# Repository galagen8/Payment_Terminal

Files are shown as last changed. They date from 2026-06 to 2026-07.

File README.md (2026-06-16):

# Payment-Donation-Terminal

A hardware and software solution designed as an automated donation terminal for a church. The system accepts cash (banknotes) and triggers electrical decorative candles to light up for a specific duration based on the donation amount.
<br><br>

<p align="center">
Finished Donation Terminal in Installation
</p>

<br>
This repository contains the complete design files, including MCU firmware, PCB layouts, and 3D mechanical models.

---

## Tech Stack & Tools

* MCU & Firmware: STM32G030K8T6 (Production), NUCLEO-F446RE (Prototyping) using STM32CubeHAL
* ECAD: Altium Designer
* MCAD: SolidWorks
* Peripherals: ICT NK77 Bill Acceptor

---

## Features

* Banknote Validation: Integrated with an ICT NK77 Bill Acceptor using a reliable pulse-based protocol.
* Cost-Optimized Hardware: Built on a budget-friendly and reliable STM32G0 MCU, utilizing STM32CubeHAL for seamless firmware portability from the initial STM32F4 prototype.
* Hardware-Driven Power Gating: Candles are hardwired and controlled via low-side NPN transistor switches, eliminating wireless reliability issues and fast battery discharge.
* Scalable Output: The custom PCB features parallel sockets for each channel, supporting up to 6 candles in total (powered by a dedicated stable 5V PSU).

---

### PCB Design & Assembly

*Actual assembled board:*

<p align="center">
Custom PCB Assembly
<p/>
<br>

*Topology / 3D visualization in Altium Designer:*

<p align="center">
Altium Designer PCB Layout
<p/>
<br>

---

### Enclosure Design & System Sub-Assembly

*3D model of the Enclosure in SolidWorks:*

<p align="center">
SolidWorks Enclosure Design
<p/>
<br>

*System Sub-Assembly and Power Distribution:*

<p align="center">
System Sub-Assembly and Power Management
<p/>
<br>

---

## How It Works & Algorithm

### 1. Power-On Self-Test (POST) / Diagnostics
Upon boot, the system runs a quick diagnostic routine: all candles light up sequentially for 1 second each to verify wiring, transistor switching, and LED functionality before entering normal operation mode.

### 2. Pulse Interfacing
The ICT NK77 Bill Acceptor is configured via DIP switches to use the pulse protocol, transmitting 1 pulse per 10 THB (e.g., a 100 THB banknote generates 10 pulses). The STM32 MCU captures and processes these incoming pulses.

### 3. Candle Control Logic
The lighting sequence dynamically scales with the donation amount, managed by a rolling timer:
* 1st Level Donation: The 1st candle lights up for 10 minutes.
* 2nd Level Donation: If another bill is inserted while the 1st candle is active, the 2nd candle turns on, and the 10-minute countdown resets for both.
* 3rd Level Donation: Subsequent insertions activate the 3rd candle and renew the master 10-minute timer.

---

## Repository Structure

* /Firmware — STM32CubeIDE project and source code (HAL-based).
* /Altium — Schematic and PCB layout files (manufactured via JLCPCB, hand-assembled).
* /SolidWorks — 3D models and manufacturing drawings for the HLP enclosure.

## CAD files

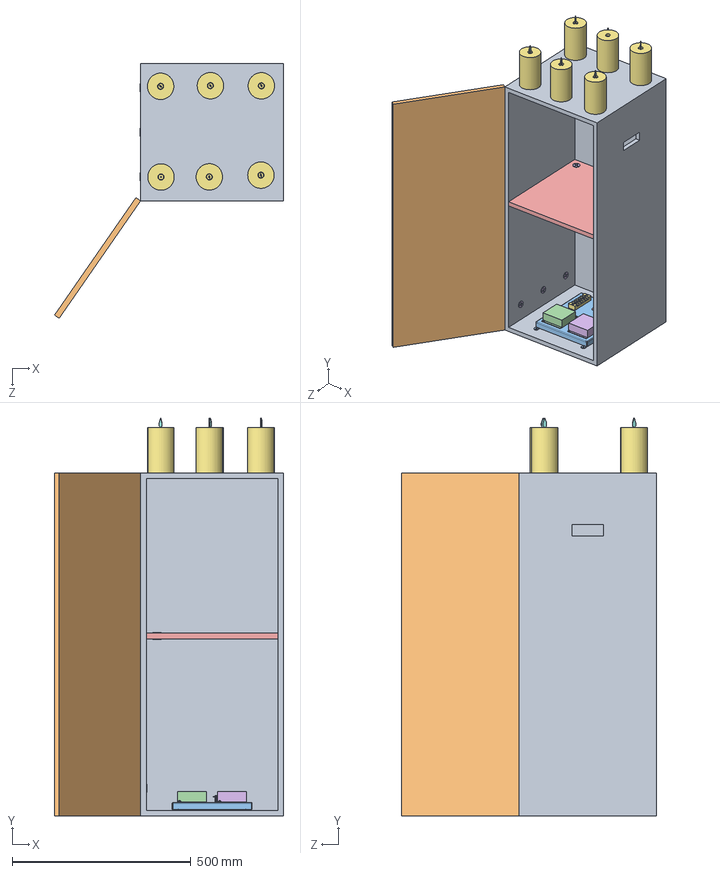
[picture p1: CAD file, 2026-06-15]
Solidworks/ASSY_WHOLE_DON-BOX_1.SLDASM
641.0 x 1114.0 x 712.7 mm
WOOD_BOX_2
WOOD_DOOR_2
SHEET_1
POWER_SUPPLY_MEANWELL_LRS-35_5V-7A_1
PCB_MOCKUP_1
POWER_SUPPLY_MEANWELL_LRS-35-12_12V-3A_1
TB-6_TERMINAL-1
BOLT_PH-M3-6MM x 4
STAND_M3_PLASTIC_1 x 4
WASHER_M3_8mm_1 x 18
BOLT_PH-M3-10MM x 6
NUT_M3_METAL_1 x 10
WOOD_SHELF_1
SLEEVE_SILICON_20MM-1 x 8
CANDLE_BODY_1 x 6
CANDLE_FLAME_1 x 6

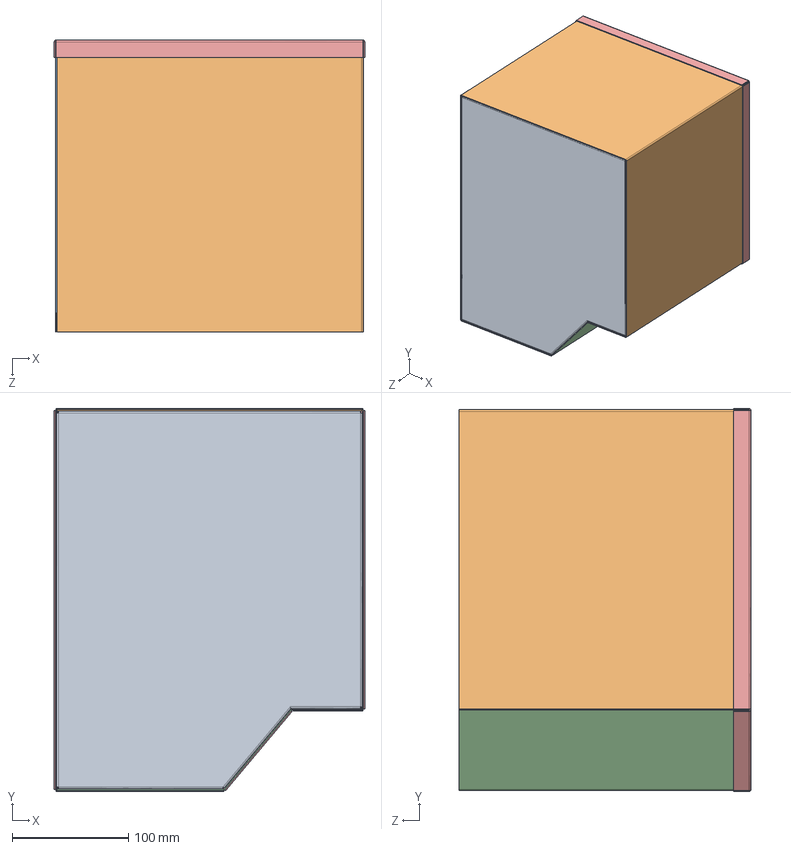
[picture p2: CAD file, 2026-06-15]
Solidworks/ASSEM_MONEY_BOX-1.SLDASM
267.0 x 329.1 x 251.0 mm
MONEY-BOX_PART_2-1
MONEY-BOX_PART_1-2
MONEY-BOX_PART_3-1
MONEY-BOX_PART_4-1
MONEY-BOX_PART_5-1

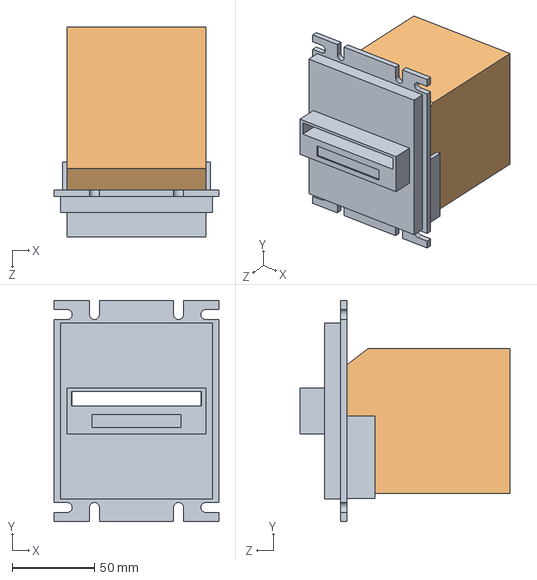
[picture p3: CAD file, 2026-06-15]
Solidworks/NK77_ASSEM_1.SLDASM
100.0 x 134.0 x 127.5 mm
NK77_COVER
NK77_ACCEPTOR

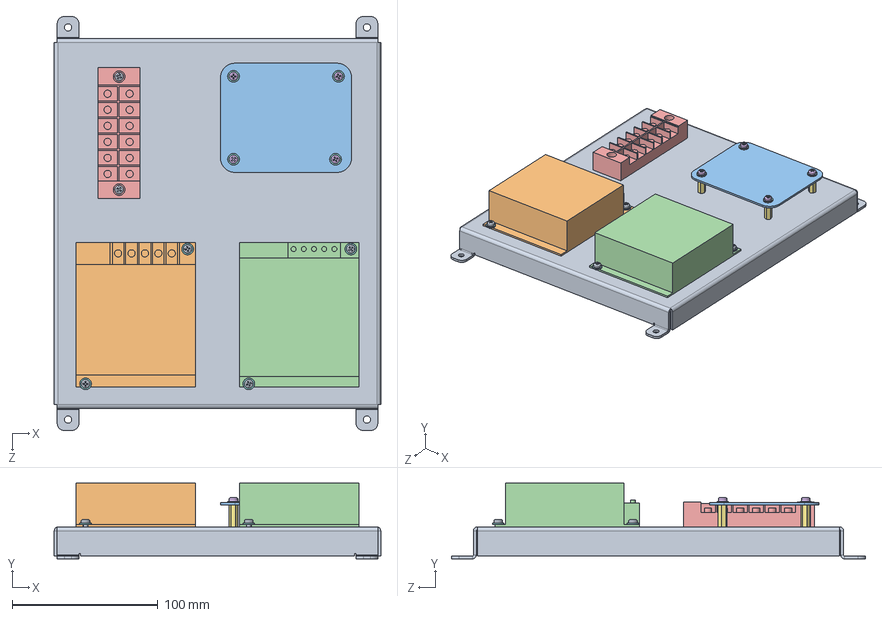
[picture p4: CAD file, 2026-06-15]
Solidworks/ASSY_SHIELD_ELEC_1.SLDASM
224.0 x 52.0 x 284.0 mm
SHEET_1
POWER_SUPPLY_MEANWELL_LRS-35_5V-7A_1
PCB_MOCKUP_1
POWER_SUPPLY_MEANWELL_LRS-35-12_12V-3A_1
TB-6_TERMINAL-1
BOLT_PH-M3-6MM x 4
STAND_M3_PLASTIC_1 x 4
WASHER_M3_8mm_1 x 18
BOLT_PH-M3-10MM x 6
NUT_M3_METAL_1 x 10

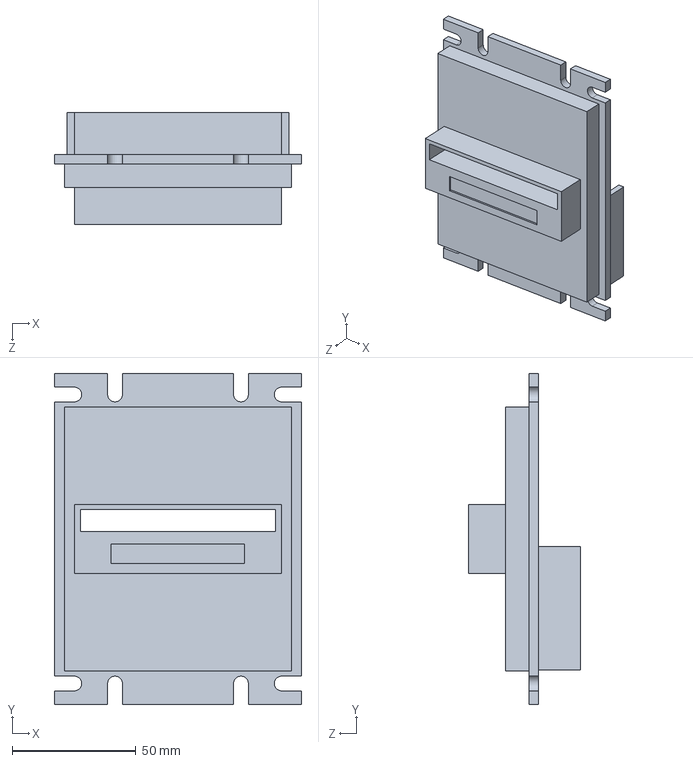
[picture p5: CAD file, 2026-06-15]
Solidworks/NK77_COVER.SLDPRT
100.0 x 134.0 x 45.5 mm

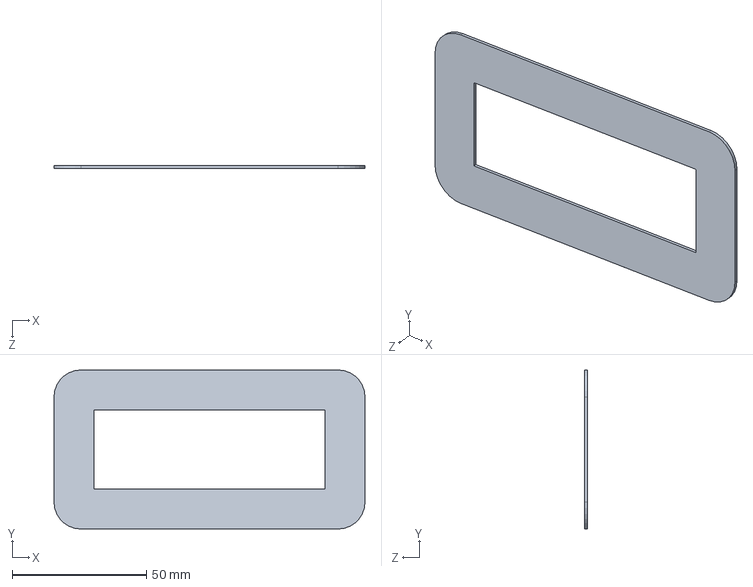
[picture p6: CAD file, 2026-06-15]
Solidworks/VISOR_NK77-1.SLDPRT
116.0 x 59.3 x 1.00 mm

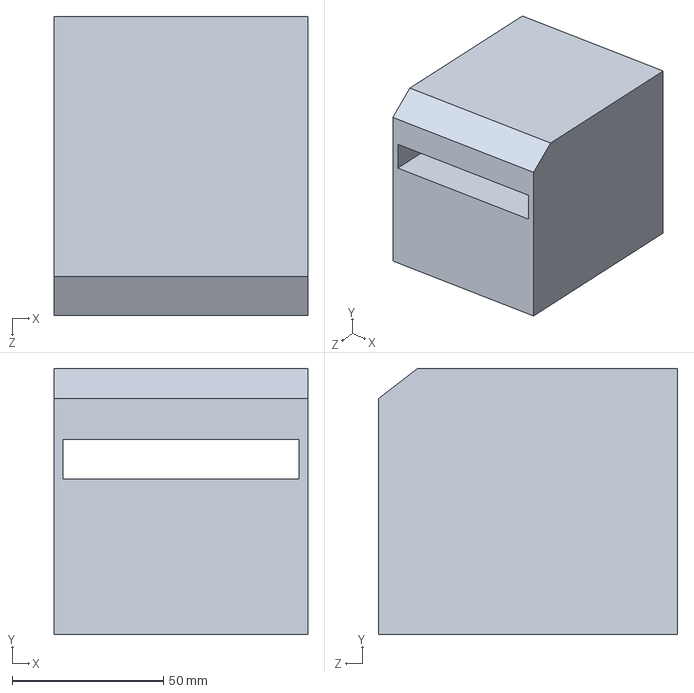
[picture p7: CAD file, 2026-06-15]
Solidworks/NK77_ACCEPTOR.SLDPRT
84.0 x 88.0 x 99.0 mm

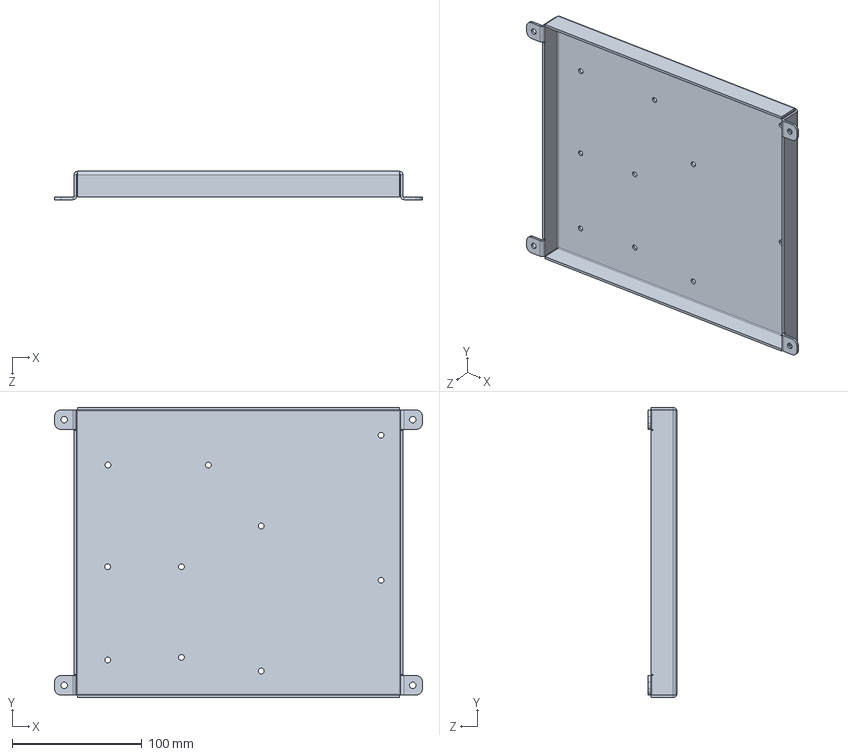
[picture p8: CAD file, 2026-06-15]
Solidworks/SHEET_1.SLDPRT
284.0 x 224.0 x 22.0 mm

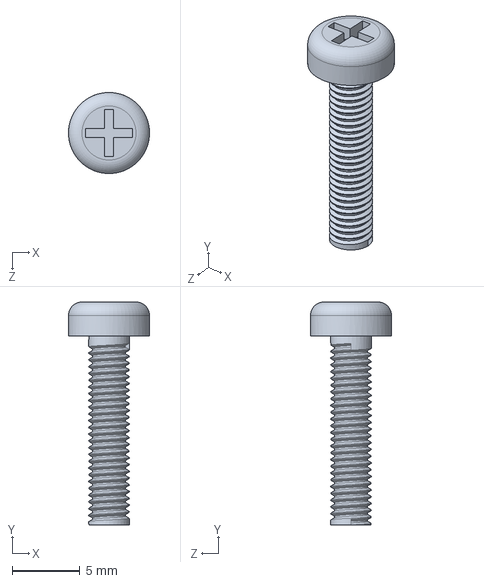
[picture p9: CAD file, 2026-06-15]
Solidworks/BOLT_PH-M3-10MM_1.SLDPRT
6.00 x 16.5 x 6.00 mm

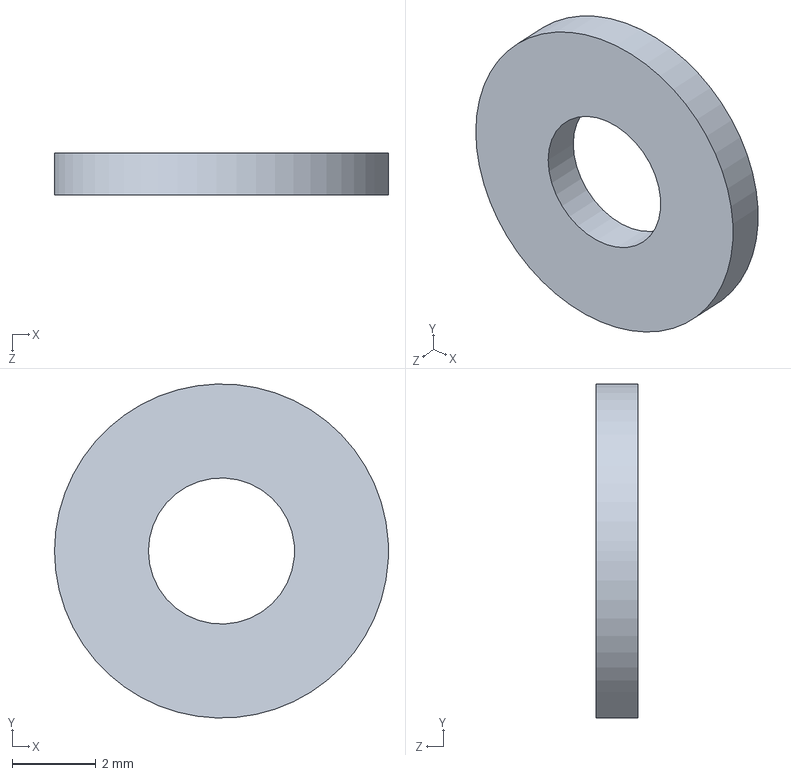
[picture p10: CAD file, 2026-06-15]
Solidworks/WASHER_M3_8mm_1.SLDPRT
8.00 x 8.00 x 1.00 mm

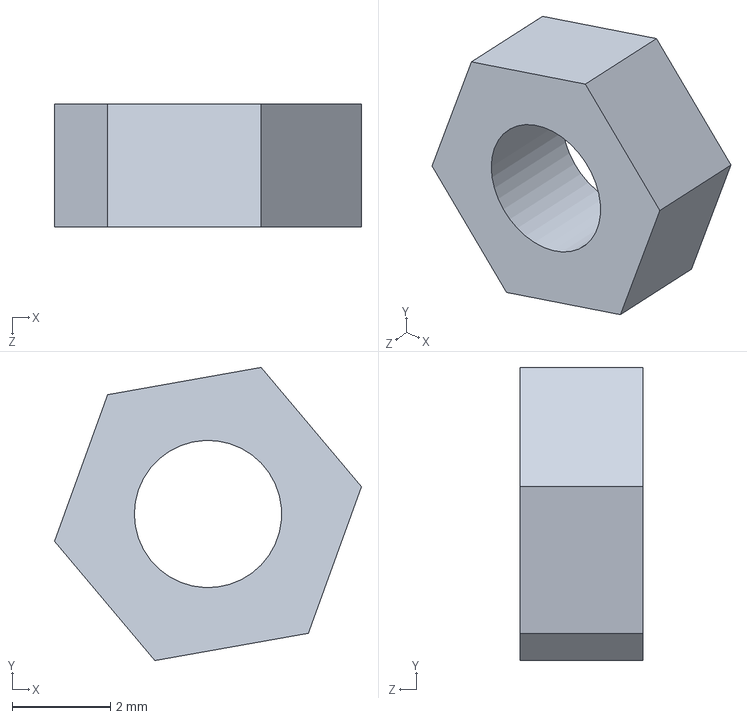
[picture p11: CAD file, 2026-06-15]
Solidworks/NUT_M3_METAL_1.SLDPRT
6.25 x 5.97 x 2.50 mm

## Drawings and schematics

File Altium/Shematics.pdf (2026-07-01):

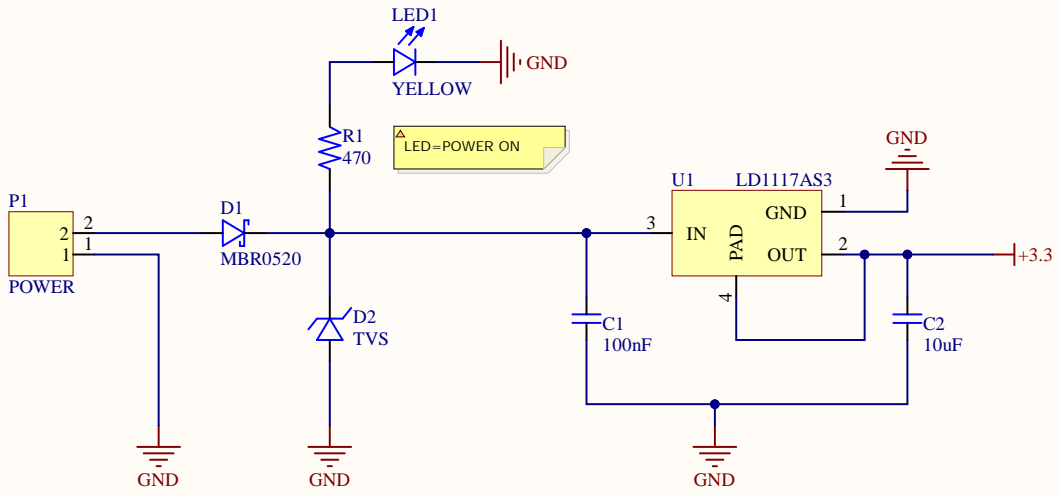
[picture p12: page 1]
Title; Size; Revisio; Date:; Sheet o; File:; K:\DG\..\Power.SchDo; Drawn B; GND; OUT; PAD 4; D2 TVS; LED1; YELLOW; POWER

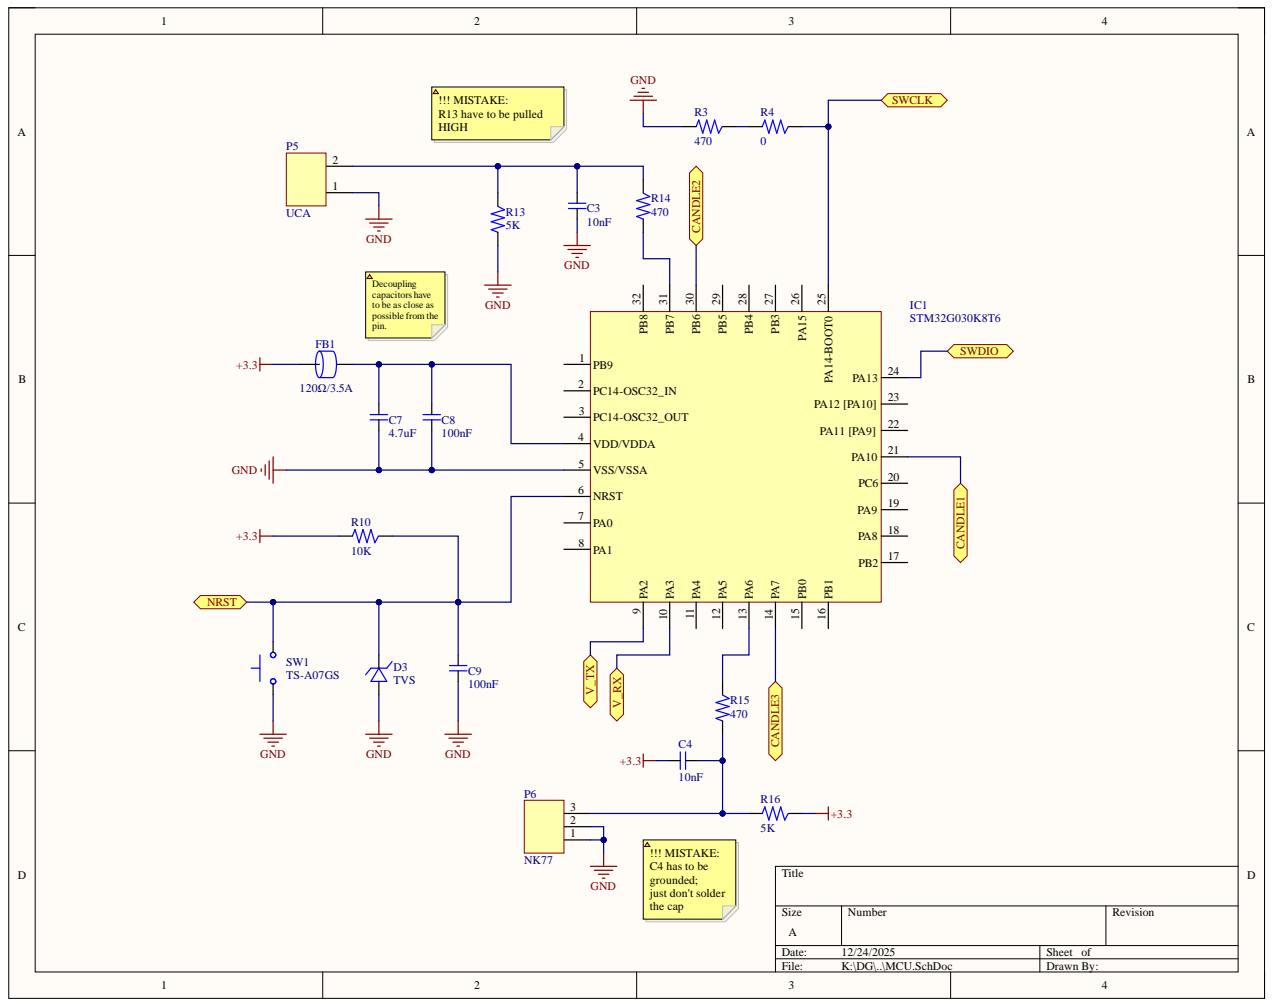
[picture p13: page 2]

!!! MISTAKE:
R13 have to be pulled
HIGH

Decoupling
capacitors have
to be as close as
possible from the
pin.

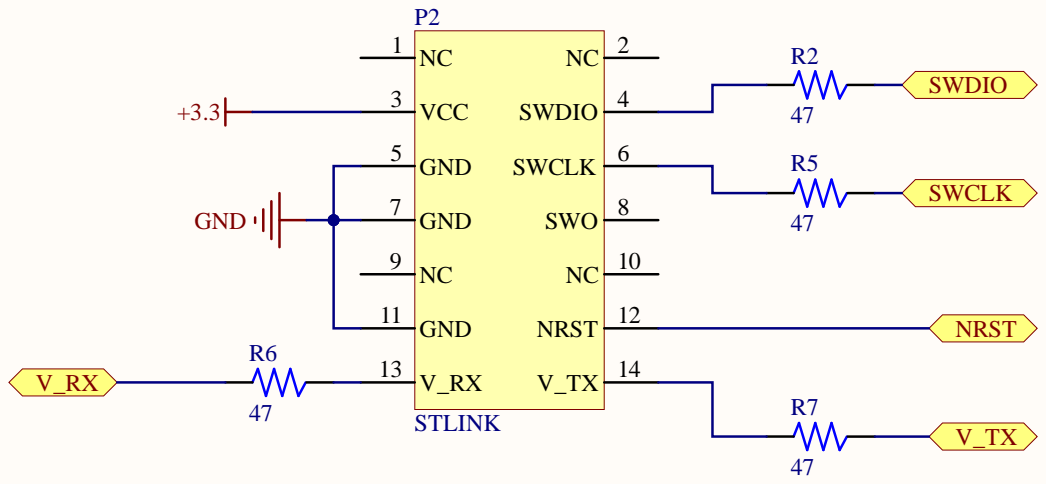
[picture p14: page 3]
Title; Size; Number; Revision; File:; K:\DG\..\STlink-plug.SchDoc; Drawn By:; VCC 3; SWDIO 4; GND 5; SWCLK 6; GND 7; SWO 8; GND 11; NRST 12; STLINK; NRST; SWDIO; SWCLK; GND

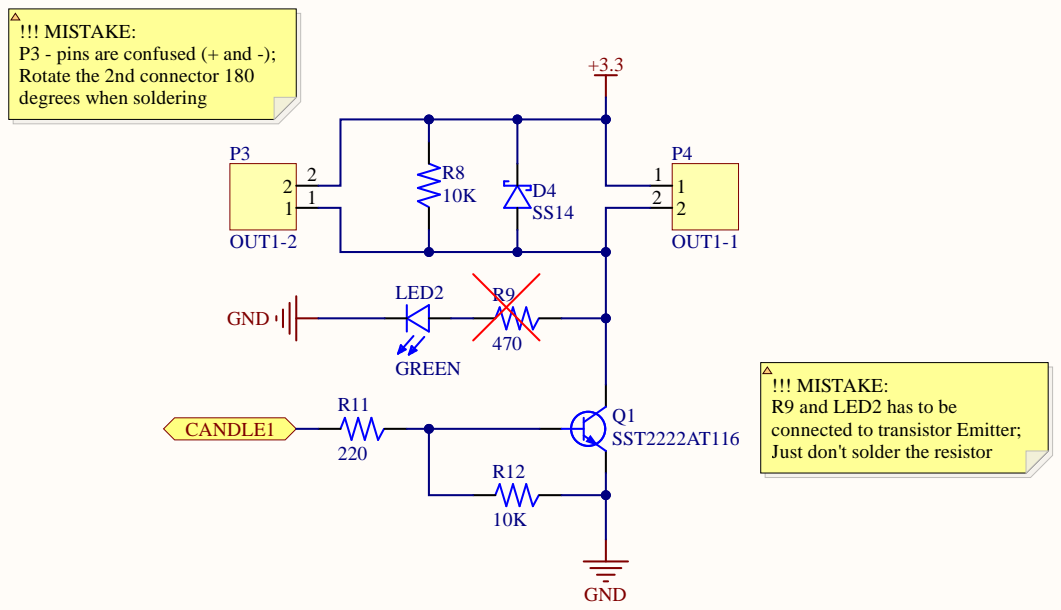
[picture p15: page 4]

!!! MISTAKE:
P3 - pins are confused (+ and -);
Rotate the 2nd connector 180
degrees when soldering

R9 and LED2 has to be
connected to transistor Emitter;
Just don't solder the resistor

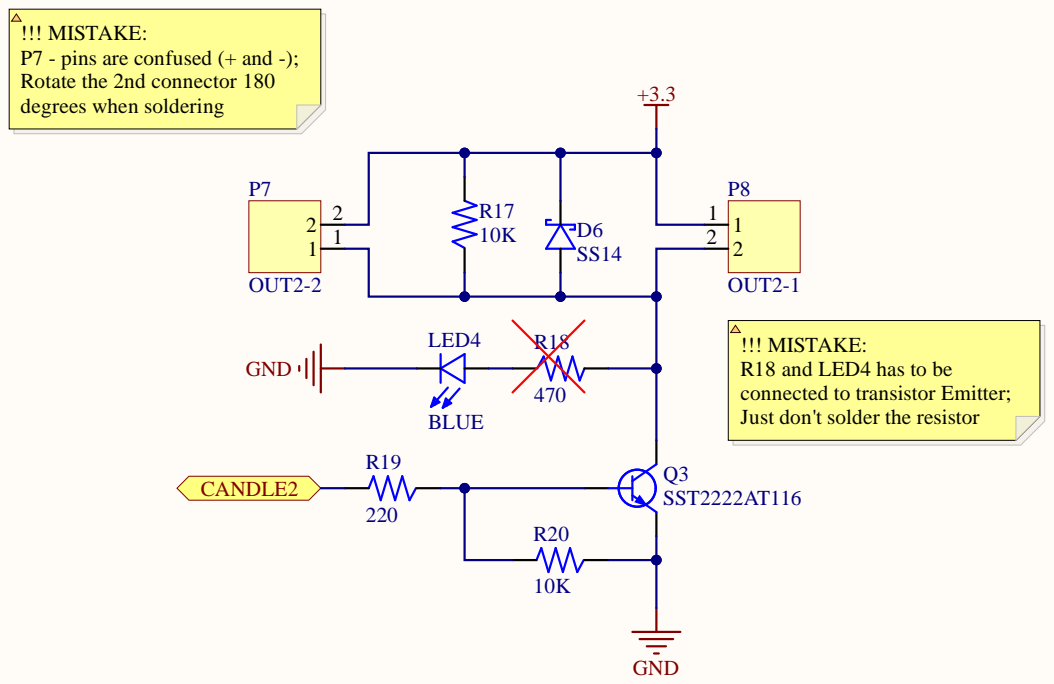
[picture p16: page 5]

!!! MISTAKE:
P7 - pins are confused (+ and -);
Rotate the 2nd connector 180
degrees when soldering

R18 and LED4 has to be
connected to transistor Emitter;
Just don't solder the resistor

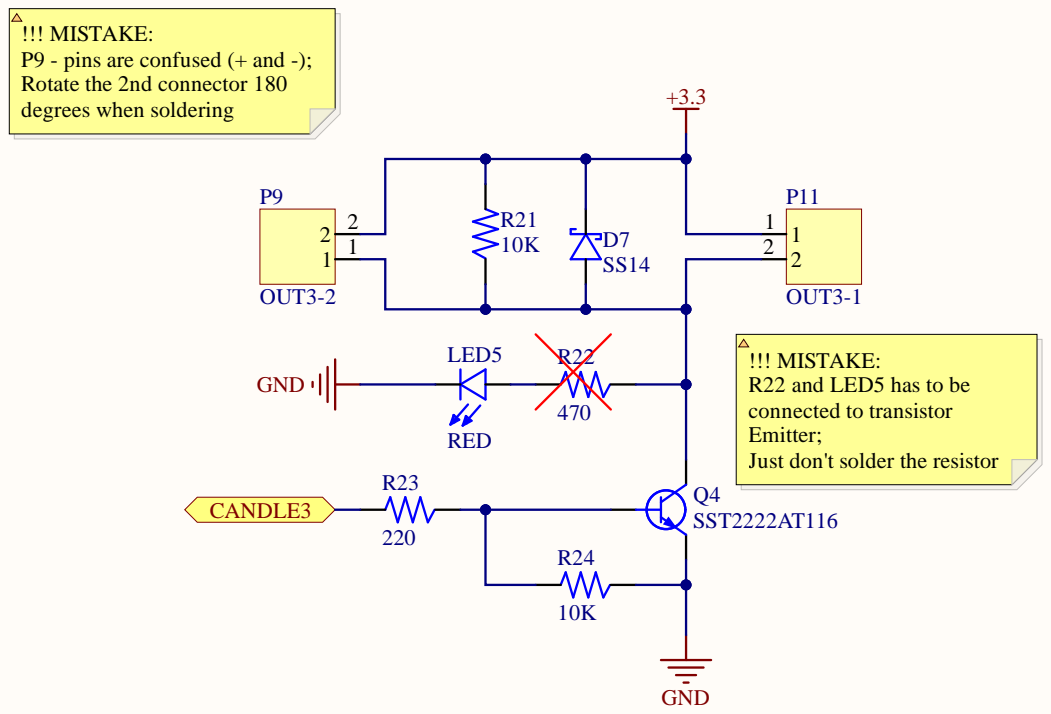
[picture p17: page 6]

!!! MISTAKE:
P9 - pins are confused (+ and -);
Rotate the 2nd connector 180
degrees when soldering

R22 and LED5 has to be
connected to transistor
Emitter;
Just don't solder the resistor
SST2222AT116

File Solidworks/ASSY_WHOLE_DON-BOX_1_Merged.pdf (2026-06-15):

# CUT

E | E

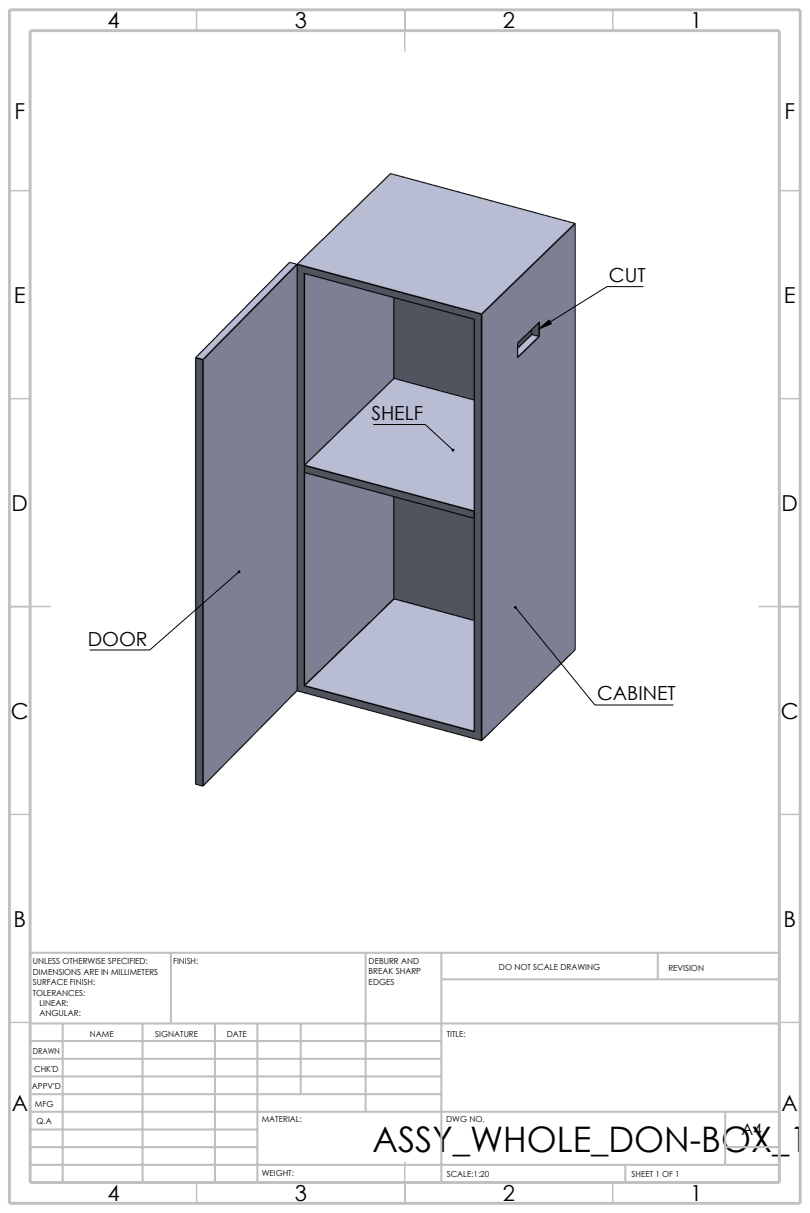
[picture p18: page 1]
DOOR; CABINET; SHELF; FINISH:; DEBURR AND; BREAK SHARP EDGES; DO NOT SCALE DRAWING; REVISION; SCALE:1:20; SHEET 1 OF 1; WEIGHT:; ASSY_WHOLE_DON-BOX_1

UNLESS OTHERWISE SPECIFIED:
DIMENSIONS ARE IN MILLIMETERS
SURFACE FINISH:
TOLERANCES:
LINEAR:
ANGULAR:

NAME | SIGNATURE | DATE | | | | TITLE:

DRAWN
CHK'D
APPV'D
MFG
Q.A | | | | MATERIAL: | DWG NO. | A4

16.00
E | E

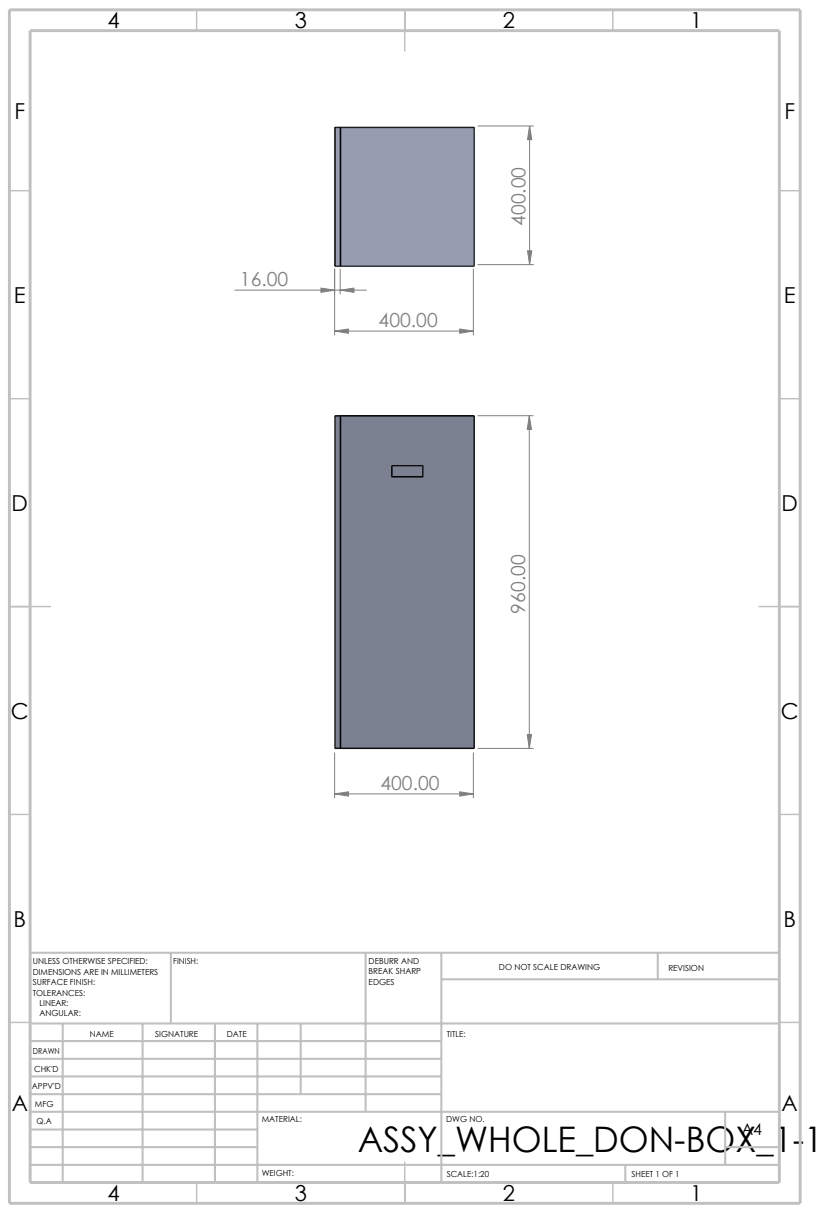
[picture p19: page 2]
FINISH:; DEBURR AND; BREAK SHARP EDGES; DO NOT SCALE DRAWING; REVISION; ASSY_WHOLE_DON-BOX_1-1

UNLESS OTHERWISE SPECIFIED:
DIMENSIONS ARE IN MILLIMETERS
SURFACE FINISH:
TOLERANCES:
LINEAR:
ANGULAR:

NAME | SIGNATURE | DATE | TITLE:

DRAWN
CHK'D
APPV'D
MFG

89.00

E | E

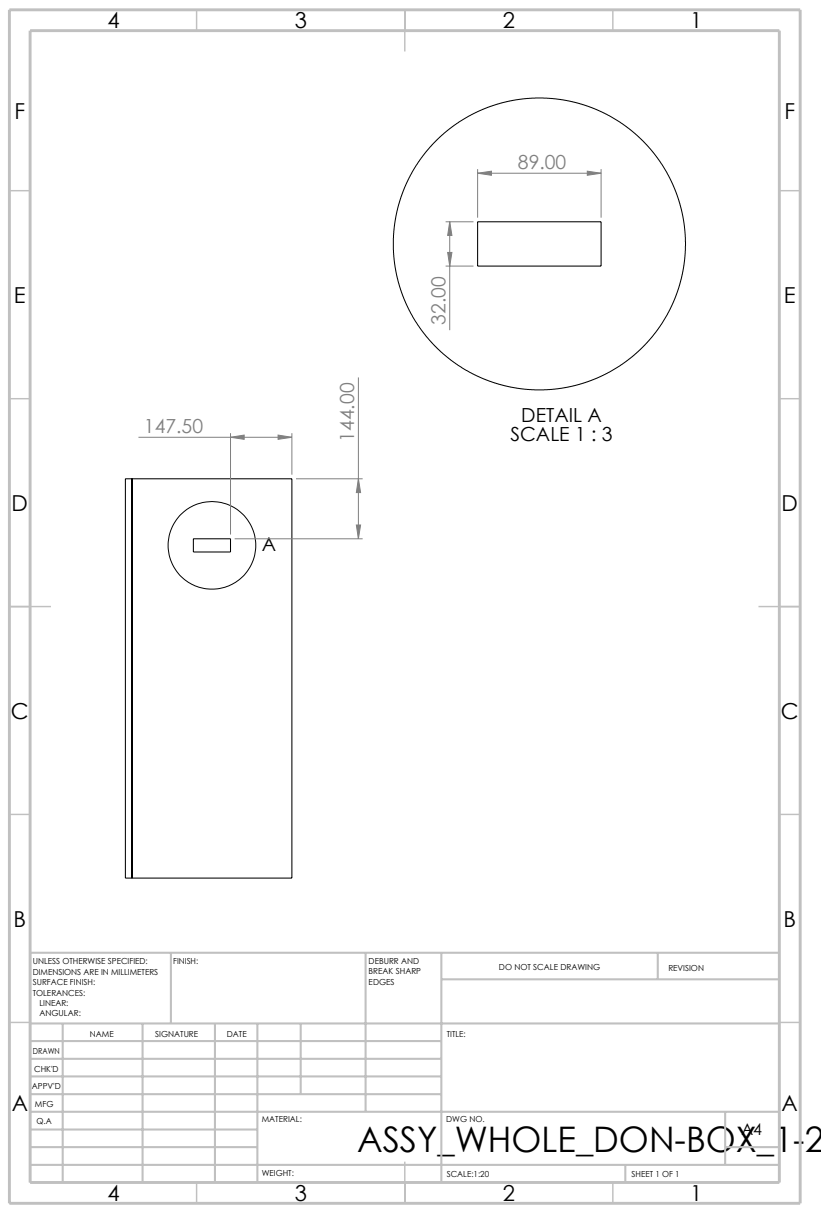
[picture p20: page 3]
DETAIL A SCALE 1 : 3; FINISH:; DEBURR AND; BREAK SHARP EDGES; DO NOT SCALE DRAWING; REVISION

UNLESS OTHERWISE SPECIFIED:
DIMENSIONS ARE IN MILLIMETERS
SURFACE FINISH:
TOLERANCES:
LINEAR:
ANGULAR:

NAME | SIGNATURE | DATE | TITLE:

DRAWN
CHK'D
APPV'D
MFG

E | E
F | F

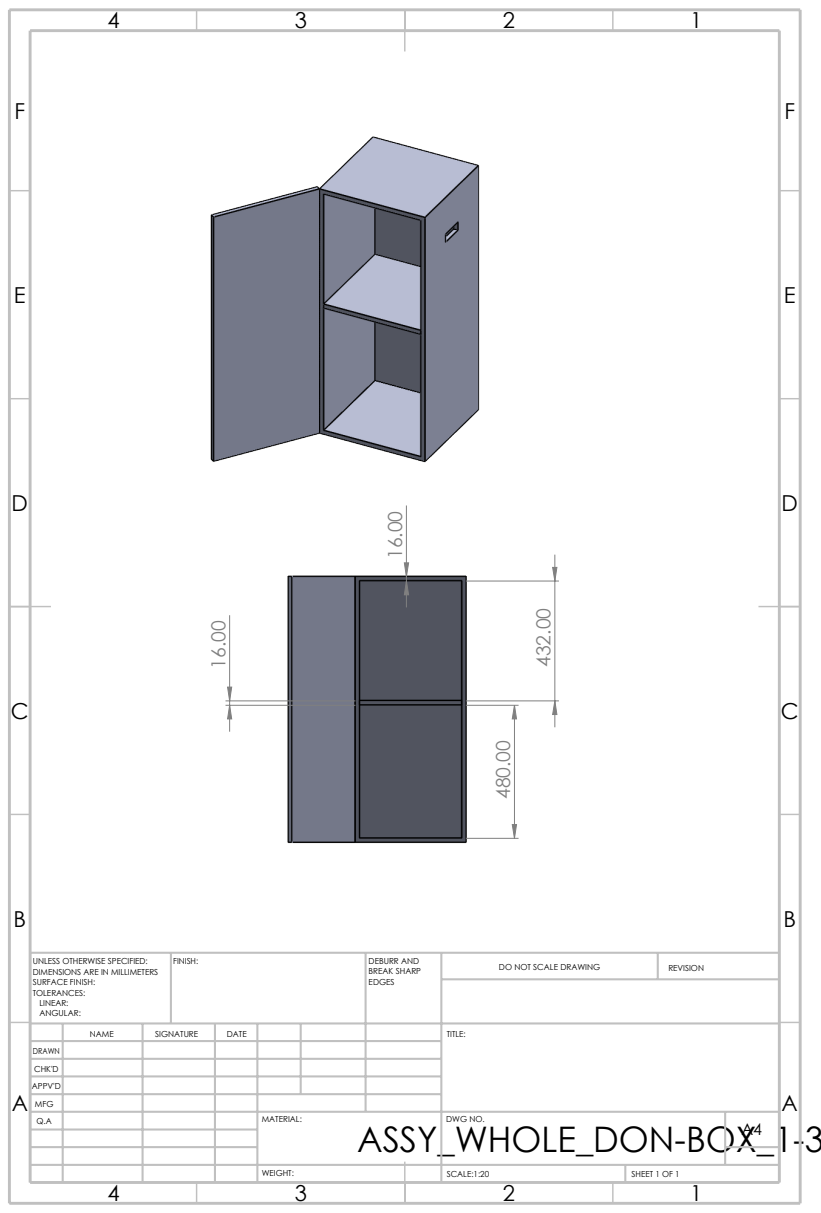
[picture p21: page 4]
FINISH:; DEBURR AND; BREAK SHARP EDGES; DO NOT SCALE DRAWING; REVISION

UNLESS OTHERWISE SPECIFIED:
DIMENSIONS ARE IN MILLIMETERS
SURFACE FINISH:
TOLERANCES:
LINEAR:
ANGULAR:

NAME | SIGNATURE | DATE | TITLE:

DRAWN
CHK'D
APPV'D
MFG

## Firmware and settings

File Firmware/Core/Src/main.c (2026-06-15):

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
/* Includes ------------------------------------------------------------------*/
#include "main.h"

/* USER CODE BEGIN PD */
#define BILL_IDLE 0
#define BILL_COUNTING 1
#define BILL_END_TIMEOUT_MS 300   // 300 мс достаточно для этого режима
#define CANDLE_TIME_MS 300000     // 5 минут
#define EARLY_VALID_PULSES 2      // зажигаем свечу после 2 импульсов — работает с 20 бат и выше, быстро (~0.2 сек)
/* USER CODE END PD */


void SystemClock_Config(void);
static void MX_GPIO_Init(void);
/* USER CODE BEGIN 0 */
/* ---- Купюроприемник ---- */
uint32_t last_edge_time = 0;
uint16_t pulse_count = 0;
uint8_t bill_state = BILL_IDLE;

uint8_t prev_pin_state = GPIO_PIN_SET;

uint8_t candle_count = 0;
uint32_t candle_off_time = 0;
uint8_t bill_processed = 0;  // 1 = купюра уже засчитана в этой серии


/* USER CODE END 0 */

/**
  * @brief  The application entry point.
  * @retval int
  */
int main(void)
{

  /* MCU Configuration--------------------------------------------------------*/

  /* Reset of all peripherals, Initializes the Flash interface and the Systick. */
  HAL_Init();

  /* Configure the system clock */
  SystemClock_Config();

  /* Initialize all configured peripherals */
  MX_GPIO_Init();
  /* USER CODE BEGIN 2 */
  /* --- STARTUP CANDLE SEQUENCE --- */

  // 3 раза поочерёдно
  /* --- STARTUP CANDLE SEQUENCE --- */

  // Поочерёдно
  HAL_GPIO_WritePin(GPIOA, GPIO_PIN_10, GPIO_PIN_SET); // CANDLE1
  HAL_Delay(500);
  HAL_GPIO_WritePin(GPIOA, GPIO_PIN_10, GPIO_PIN_RESET);

  HAL_GPIO_WritePin(GPIOB, GPIO_PIN_6, GPIO_PIN_SET);  // CANDLE2
  HAL_Delay(500);
  HAL_GPIO_WritePin(GPIOB, GPIO_PIN_6, GPIO_PIN_RESET);

  HAL_GPIO_WritePin(GPIOA, GPIO_PIN_7, GPIO_PIN_SET);  // CANDLE3
  HAL_Delay(500);
  HAL_GPIO_WritePin(GPIOA, GPIO_PIN_7, GPIO_PIN_RESET);

  // Все вместе на 1 секунду
  HAL_GPIO_WritePin(GPIOA, GPIO_PIN_10, GPIO_PIN_SET);
  HAL_GPIO_WritePin(GPIOB, GPIO_PIN_6, GPIO_PIN_SET);
  HAL_GPIO_WritePin(GPIOA, GPIO_PIN_7, GPIO_PIN_SET);
  HAL_Delay(500);

  // Гасим в обратном порядке
  HAL_GPIO_WritePin(GPIOA, GPIO_PIN_7, GPIO_PIN_RESET); // CANDLE3
  HAL_Delay(500);

  HAL_GPIO_WritePin(GPIOB, GPIO_PIN_6, GPIO_PIN_RESET); // CANDLE2
  HAL_Delay(500);

  HAL_GPIO_WritePin(GPIOA, GPIO_PIN_10, GPIO_PIN_RESET); // CANDLE1
  HAL_Delay(500);

  // Инициализируем prev_pin_state реальным состоянием пина
  prev_pin_state = HAL_GPIO_ReadPin(GPIOA, GPIO_PIN_6);

  /* --- END OF STARTUP SEQUENCE --- */


  /* --- END OF STARTUP SEQUENCE --- */
  // Правильная инициализация состояния датчика после старта
    prev_pin_state = HAL_GPIO_ReadPin(GPIOA, GPIO_PIN_6);
    last_edge_time = HAL_GetTick();
    bill_state = BILL_IDLE;
    pulse_count = 0;
    candle_count = 0;
    candle_off_time = 0;

  /* USER CODE END 2 */

  /* Infinite loop */
  /* USER CODE BEGIN WHILE */
  while (1)
  {
    /* USER CODE END WHILE */

    /* USER CODE BEGIN 3 */
	  uint32_t now = HAL_GetTick();

	  uint8_t pin_state = HAL_GPIO_ReadPin(GPIOA, GPIO_PIN_6);

	  /* ---------- Детекция импульса (FALLING EDGE) ---------- */
	  if (prev_pin_state == GPIO_PIN_SET && pin_state == GPIO_PIN_RESET)
	  {
		  last_edge_time = now;

		  if (bill_state == BILL_IDLE)
		  {
			  bill_state = BILL_COUNTING;
			  pulse_count = 0;
			  bill_processed = 0;
		  }

		  pulse_count++;

		  // Зажигаем одну свечу только один раз — после 2 импульсов
		  if (bill_state == BILL_COUNTING && pulse_count >= EARLY_VALID_PULSES && bill_processed == 0)
		  {
			  bill_processed = 1;

			  if (candle_count < 3)
			  {
				  candle_count++;

				  HAL_GPIO_WritePin(GPIOA, GPIO_PIN_10, (candle_count >= 1) ? GPIO_PIN_SET : GPIO_PIN_RESET);
				  HAL_GPIO_WritePin(GPIOB, GPIO_PIN_6, (candle_count >= 2) ? GPIO_PIN_SET : GPIO_PIN_RESET);
				  HAL_GPIO_WritePin(GPIOA, GPIO_PIN_7, (candle_count >= 3) ? GPIO_PIN_SET : GPIO_PIN_RESET);

				  candle_off_time = now + CANDLE_TIME_MS;
			  }
			  else
			  {
				  candle_off_time = now + CANDLE_TIME_MS;
			  }
		  }
	  }

	  prev_pin_state = pin_state;

	  /* ---------- Конец серии импульсов ---------- */
	  if (bill_state == BILL_COUNTING && (now - last_edge_time) > BILL_END_TIMEOUT_MS)
	  {
		  bill_state = BILL_IDLE;
		  pulse_count = 0;
		  bill_processed = 0;
	  }

	  /* ---------- Выключение свечей по таймеру ---------- */
	  if (candle_count > 0 && now >= candle_off_time)
	  {
		  HAL_GPIO_WritePin(GPIOA, GPIO_PIN_10, GPIO_PIN_RESET);
		  HAL_GPIO_WritePin(GPIOB, GPIO_PIN_6, GPIO_PIN_RESET);
		  HAL_GPIO_WritePin(GPIOA, GPIO_PIN_7, GPIO_PIN_RESET);

		  candle_count = 0;
	  }
  }
  /* USER CODE END 3 */
}

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


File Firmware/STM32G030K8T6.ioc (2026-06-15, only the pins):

Mcu.UserName=STM32G030K8Tx
PA10.Signal=GPIO_Output
PA6.Signal=GPIO_Input
PA7.Signal=GPIO_Output
PB6.Signal=GPIO_Output

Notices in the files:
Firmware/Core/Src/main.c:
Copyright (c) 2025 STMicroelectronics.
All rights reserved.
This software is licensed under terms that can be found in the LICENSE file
